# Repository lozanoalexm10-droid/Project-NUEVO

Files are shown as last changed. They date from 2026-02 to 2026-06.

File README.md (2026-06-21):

# MARSY

> **Mobile Autonomous Robotic SYstem**

| | | |
|---|---|---|
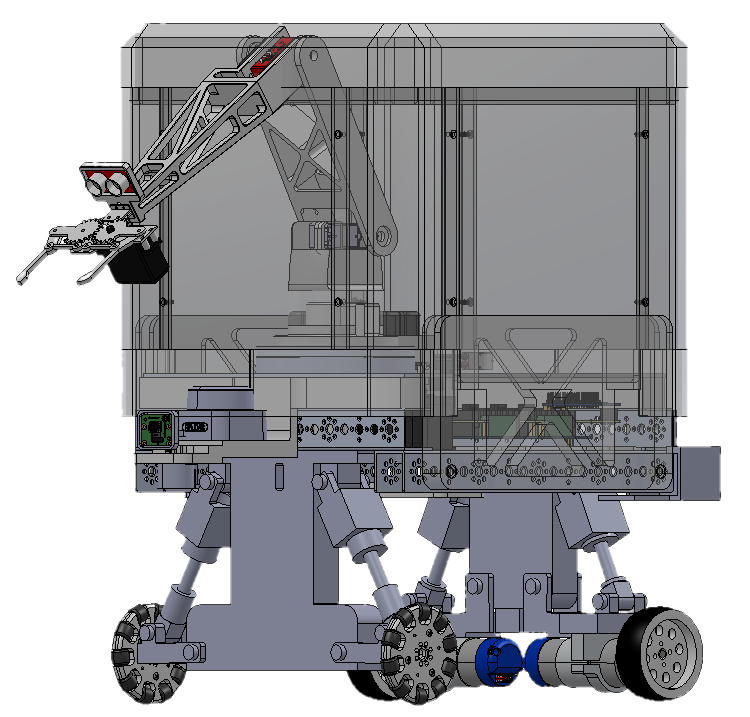
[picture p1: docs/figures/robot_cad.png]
Full assembly CAD
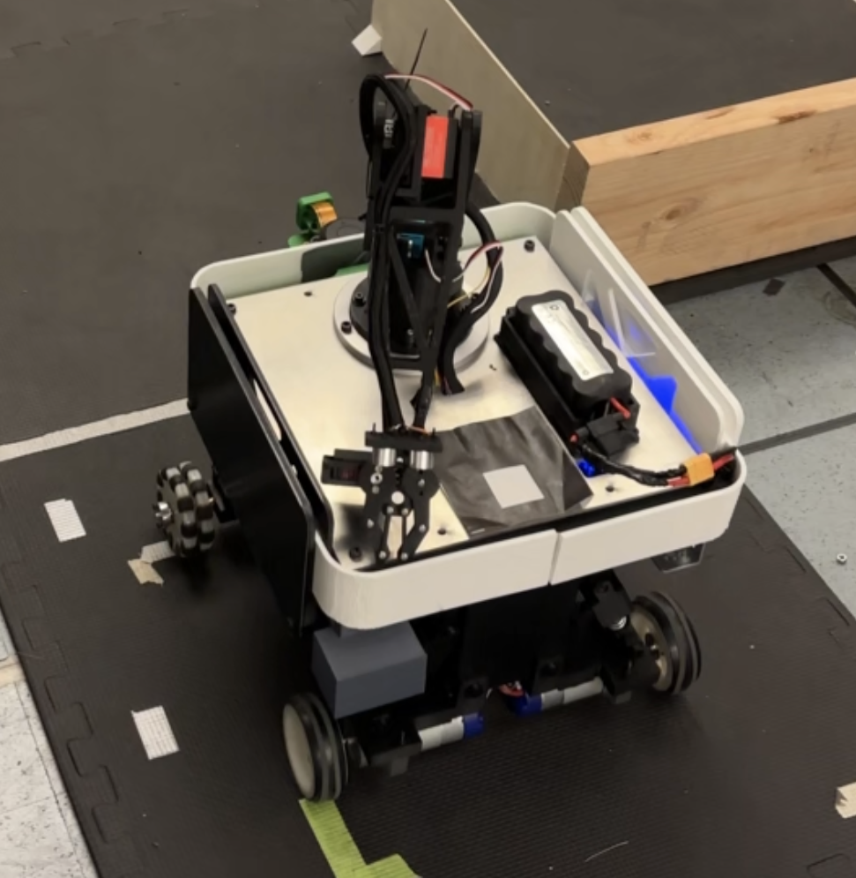
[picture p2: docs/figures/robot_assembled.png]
Operating configuration
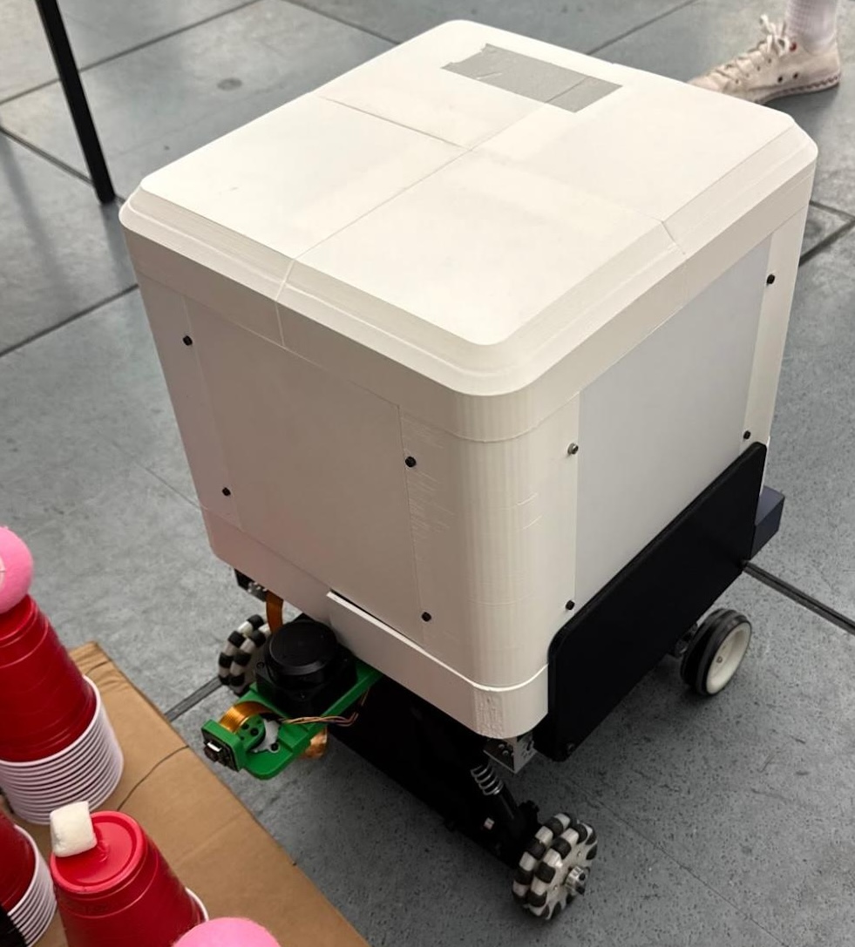
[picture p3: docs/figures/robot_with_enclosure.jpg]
Protective enclosure installed for drop and impact tests
|  |  |  |
| Full assembly CAD | Operating configuration (driving and manipulation) | Protective enclosure installed for the drop and impact tests |

MARSY is an autonomous differential-drive mobile manipulator built for the MAE 162D/E capstone, on top of the course's shared NUEVO electronics and firmware base. It drives a multi-segment competition course with LiDAR obstacle avoidance, then uses vision-guided inverse kinematics to identify the marshmallow-bearing cup stack, pick from it, and place the marshmallow on a plate.

---

## Project Overview

The team's contribution is the physical robot and the high-level autonomy program. The teaching team supplied a shared base that all capstone teams build on: a custom PCB, the Arduino firmware that drives it, the TLV link to the Pi, and a ROS 2 node skeleton.

From a kit of four aluminum U-channel pieces, two driven wheels, two omni wheels, and DC motors with mounts, we designed and built the chassis, the suspension, and a 3-DOF manipulator around a purchased metal gripper.

On top of the provided software we wrote the manipulator program for vision-guided cup-stack selection, closed-form inverse kinematics, and the pick-and-place FSM. We brought up and calibrated every sensor and actuator on the robot, added our own ROS 2 nodes where the skeleton didn't cover what we needed (e.g., the ultrasonic ranger), tuned the drive PID against encoder feedback, and reworked the provided pure-pursuit follower and obstacle-avoidance planner for the venue course.

See it run:

https://www.youtube.com/watch?v=NkwrqGURsrY

---

## Problem

Build a mobile manipulator that, with no operator intervention after a green-light go signal, can:

1. Navigate a multi-lane course at a competition venue, respecting lane geometry, an obstacle field, and a stop sign.
2. Park at a manipulation station and locate a single marshmallow that sits on one of four cup stacks of varying height.
3. Pick the marshmallow with a metal gripper, optionally roast it on a heating wire, and place it on a plate at a fixed offset.

Constraints:
- Hard real-time motor control on an Arduino Mega 2560, all higher logic on a Raspberry Pi 5.
- Communication between the two is a custom TLV protocol over a single UART link.
- A custom PCB integrates power delivery, motor drivers, and the Arduino footprint into a single board.
- No off-the-shelf navigation or manipulation stack. Perception, kinematics, and the demo FSM were written from scratch for this platform; pure-pursuit and the obstacle-avoidance planner were provided as starter code and reworked for the venue.

---

## Design and Approach

| Layer | Notes |
|---|---|
| **Mechanical** | Team-designed and team-built. Chassis, suspension, and a 3-DOF arm (turntable + shoulder + elbow) on a stepper-driven base, plus a camera-pan stepper, built from a starter kit (4 aluminum U-channels, 2 driven wheels, 2 omni wheels, DC motors + mounts), and a purchased metal gripper end effector. CAD in [`mechanical/`](mechanical/). A heating-wire roaster was designed and wired into the FSM but never installed mechanically (see Results). |
| **Custom PCB** | Provided by the teaching team. Arduino Mega 2560, dual DC motor drivers, stepper drivers, PCA9685 servo bus, LM61460 regulation. See [`nuevo_board/`](nuevo_board/). |
| **Arduino firmware** | Provided by the teaching team. Real-time motor PID, encoder odometry, stepper move queues, servo outputs, IMU + voltage monitoring, state-machine safety, and the TLV transport ([`firmware/`](firmware/), [`tlv_protocol/`](tlv_protocol/)). Drive PID gains were tuned by the team against the as-built drivetrain. |
| **Sensors** | Sensor selection was provided. The team mounted, wired, and calibrated the RPLIDAR C1, IMX477 camera, and Qwiic ultrasonic. The external GPS/ArUco localizer was built by the teaching team. The ICM-20948 IMU was dropped for the final demo due to magnetic interference from the electronics. |
| **ROS 2 stack** | Skeleton supplied (`bridge` TLV ⇆ ROS, `bridge_interfaces` msg/srv defs, `sensors`, `rplidar_ros`, `global_gps`, and the Robot API scaffolding inside `robot`). Team-added: ROS 2 nodes the skeleton didn't cover (e.g., the ultrasonic ranger), the `vision` package, and the high-level program inside the `robot` package consisting of FSMs, demo programs, manipulation code, and the perception/navigation integration that runs the demo ([`ros2_ws/src/`](ros2_ws/src/)). |
| **Perception** | Team-written. Detection for traffic lights, stop signs, marshmallows, and red cups, built on YOLO library pull-ins that the teaching team provided for the traffic-light and stop-sign detectors. |
| **Navigation** | Pure-pursuit follower and obstacle-avoidance scaffolding provided as starter code. Avoidance works by lane-switch waypoint regeneration: when a cone is detected, the planner inserts a hat-shaped detour (entry → hold past obstacle → return to center) into the remaining waypoint list. Team retuned both, added goal-y filtering so perimeter walls don't trigger detours, and wrote the four-segment venue FSM with a manual-reposition hold between segments. |
| **Manipulation** | Team-written. Closed-form 3-DOF inverse kinematics ([`arm_kinematics.py`](ros2_ws/src/robot/robot/arm_kinematics.py)) with explicit elbow-up branch selection; vision-driven stack selection; ultrasonic reach refinement; pick-and-place FSM. Documented in [`docs/manipulator.md`](docs/manipulator.md). |

### Software organization

The robot package follows a clean layout under `robot/programs/`:

```
robot/programs/
  demos/         the two headline programs
  navigation/    drive-only tests
  manipulation/  arm, servo, stepper, gripper, turntable, campan
  perception/    vision + lidar
  analysis/      data recording + plotting
  legacy/        archived earlier drafts
```

The two demo entry points are:
- [`full_competition_venue_run.py`](ros2_ws/src/robot/robot/programs/demos/full_competition_venue_run.py) for the full graded course
- [`precision_stack_manipulator_demo.py`](ros2_ws/src/robot/robot/programs/demos/precision_stack_manipulator_demo.py) for vision-driven pick-and-place

### Algorithms worth highlighting

- **Lane-switch waypoint-regeneration avoidance**: when a cone is detected, the planner inserts a hat-shaped detour into the remaining pure-pursuit path, with a goal-y filter that prevents the north wall from triggering detours.
- **Cup-pair vision detection** that confirms a marshmallow by matching its bearing against the nearest red-cup detection which is robust against tennis-ball decoys and false positives.
- **Closed-form IK with explicit branch selection**: the elbow can only fold one way, so we always select the "elbow up" branch deterministically.

---

## Results

The robot ran the venue course end-to-end and the manipulator ran the pick-and-place in isolation. The live demo had four visible issues that this section is honest about: the gripper would not release the marshmallow at the place pose, heading drift forced three manual repositions, the obstacle pass clipped one cone in the tight scenario, and odometry drift across a full venue run pushed the robot off the hardcoded cup positions, so the driving and the precision pick-and-place were demoed as separate programs. The platform itself (the team's mechanical build on top of the provided electronics and firmware) held up through the run.

### What worked

- **Full 4-segment venue navigation** including a U-turn, lane switch, and obstacle field
- **LiDAR lane-switch obstacle avoidance** (provided pure-pursuit avoidance planner, retuned for the venue) cleared 2 of 3 cones in the final run
- **Vision-guided stack selection** over the four hardcoded cup-stack positions: the vision selector reliably picks which stack contains the marshmallow when the robot starts from the known manipulation pose
- **Closed-form 3-DOF inverse kinematics** for both pick and place targets with deterministic elbow-up branch selection; the pick action ran end-to-end (place release did not; see below)
- **Localization**: the provided wheel-odometry + GPS/ArUco fusion kept the robot tracking the course (the ICM-20948 IMU was dropped for the final demo due to magnetic interference)
- **Stop-sign and traffic-light detection** in isolation during development
- **Protective enclosure passed both impact tests**: a basketball dropped onto the enclosure from 1 m and the robot itself dropped from 1 ft onto mats; the only damage was the press-fit top lid coming loose on impact, with no functional hardware harmed

### What didn't work in the live demo

- **Place-onto-plate release**: IK and FSM for the place pose were correct, and the gripper opened reliably at the pick pose, but would not open at the place pose. Most likely cause: the place reach extends the arm sideways with the gripper near-horizontal, gravity-loading the jaw closed against the MG996R's torque budget. A shoulder unload-lift (`UNLOAD_LIFT_DEG = 10°` in [`precision_stack_manipulator_demo.py`](ros2_ws/src/robot/robot/programs/demos/precision_stack_manipulator_demo.py)) wasn't enough to resolve it in the time we had.
- **Heading drift → three manual repositions**: the FSM intentionally pauses at segment boundaries (`MANUAL_REPOSITION_HOLD_S`) so the operator can re-place the robot at a known pose. We leaned on this hold rather than fighting drift autonomously.
- **Cone contact in the tight scenario**: the lane-switch avoidance cleared 2 of 3 cones but clipped one in the tight obstacle layout.
- **Stop-sign trigger didn't fire**: on the final run the robot drifted too far left of the lane center, and the stop sign sits on the far right of the lane, so the detector's range/bearing gate didn't trip. The detector usually works; we just didn't get enough end-to-end runs across the full demo to harden it, so the cause is essentially "robot was outside the gate region for this specific run." Code remains, gated by `STOP_SIGN_GATE_Y_MM` in [`full_competition_venue_run.py`](ros2_ws/src/robot/robot/programs/demos/full_competition_venue_run.py).
- **Integrated drive + pick (demos split)**: our first plan was to localize the marshmallow in free space with onboard sensors; that wasn't reliable, so we fell back to hardcoding the four candidate cup-stack positions and using vision only to pick among them. Even with the fallback, odometry drift after a full venue run left the robot off-pose relative to those hardcoded positions and the gripper would land in the wrong spot, so we ended up demoing the venue navigation and the precision pick-and-place as separate programs ([`full_competition_venue_run.py`](ros2_ws/src/robot/robot/programs/demos/full_competition_venue_run.py) and [`precision_stack_manipulator_demo.py`](ros2_ws/src/robot/robot/programs/demos/precision_stack_manipulator_demo.py)).

### What we cut

- **Heating-wire roast cycle**: software complete (the `PLACING → ROASTING` FSM transition and relay control path are wired in), but never installed in hardware. We couldn't find a safe way to mount an exposed heated element on a moving arm without unacceptable damage or burn risk, so the stage was cut by choice.

### Reference figures

| | |
|---|---|
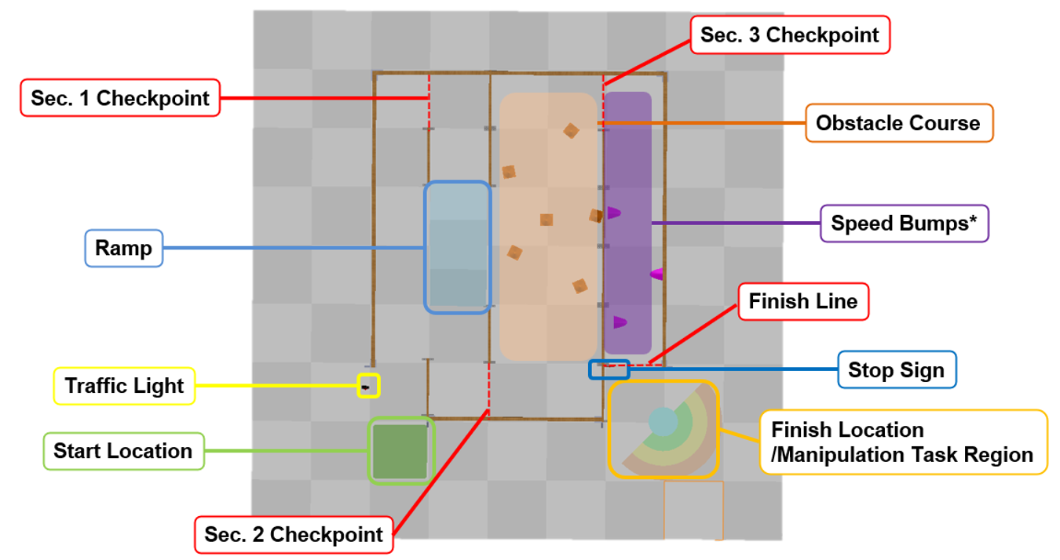
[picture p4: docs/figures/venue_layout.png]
Venue layout
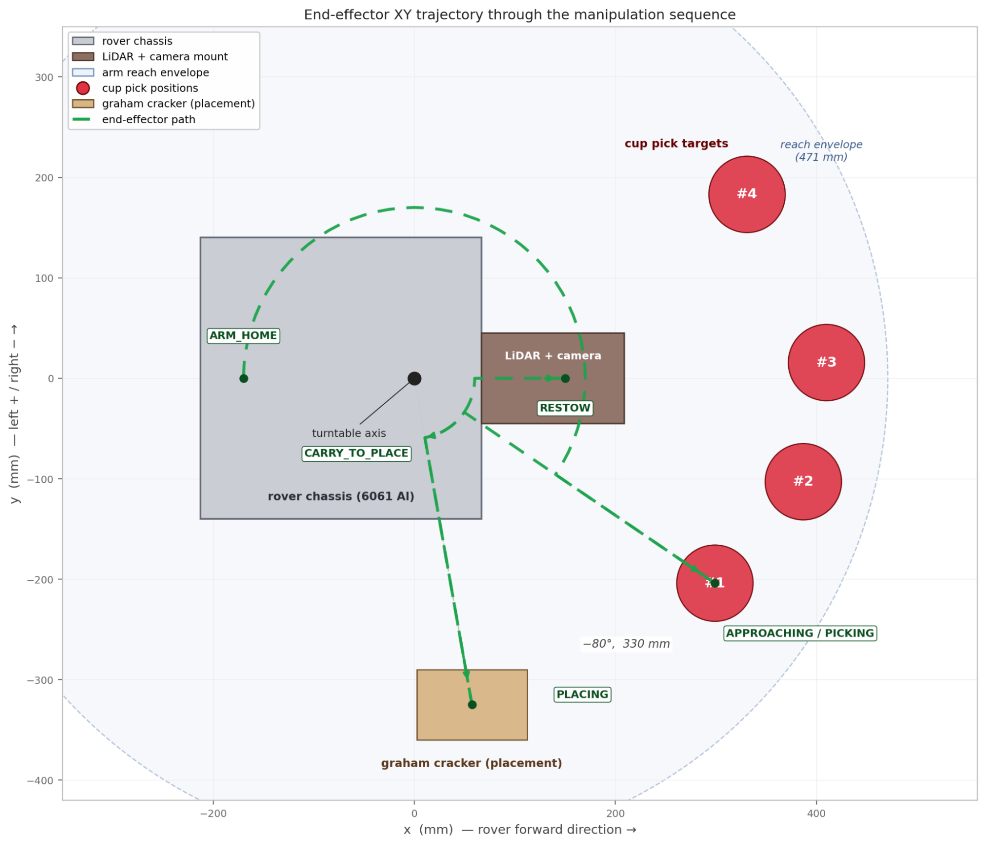
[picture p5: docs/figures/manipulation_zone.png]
Manipulation zone
|  |  |
| Annotated venue: start, segment checkpoints, ramp, obstacle course, traffic light, stop sign, finish line, and the manipulation task region. | Top-down view of the manipulation zone showing the rover footprint, LiDAR/camera mount, arm reach envelope, the four hardcoded cup-pick positions, the graham-cracker placement target, and a sample end-effector path. |
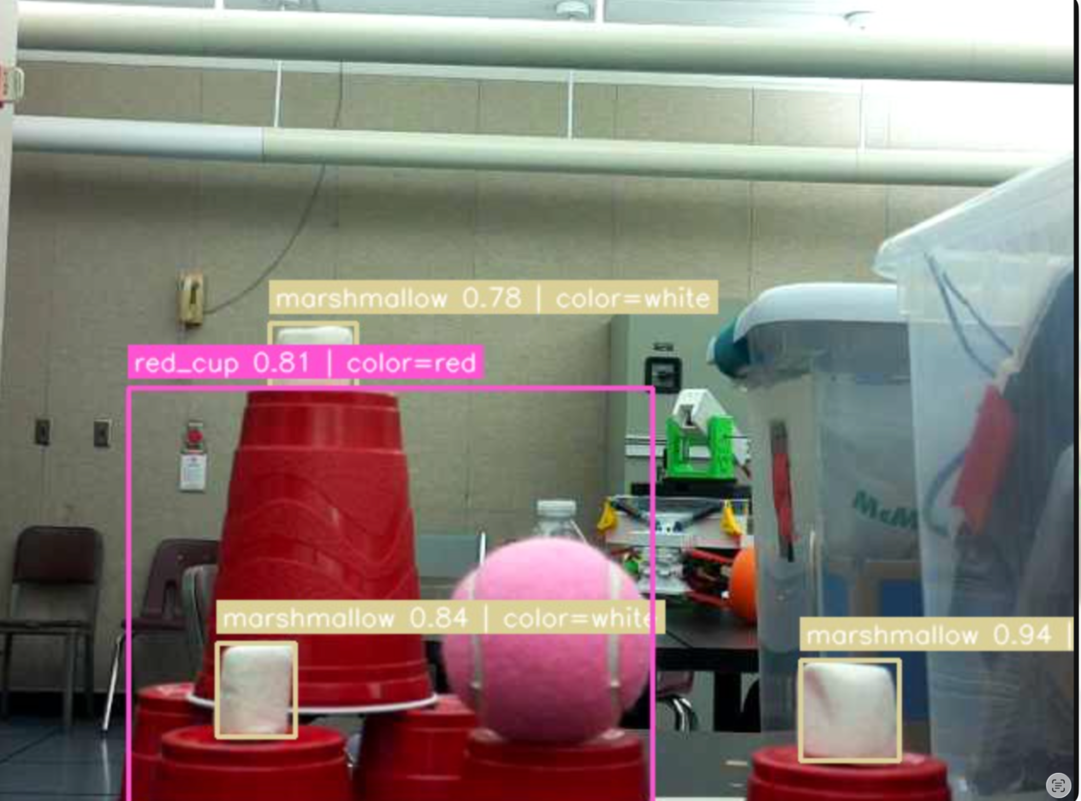
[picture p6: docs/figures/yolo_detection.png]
YOLO detection on a venue snapshot
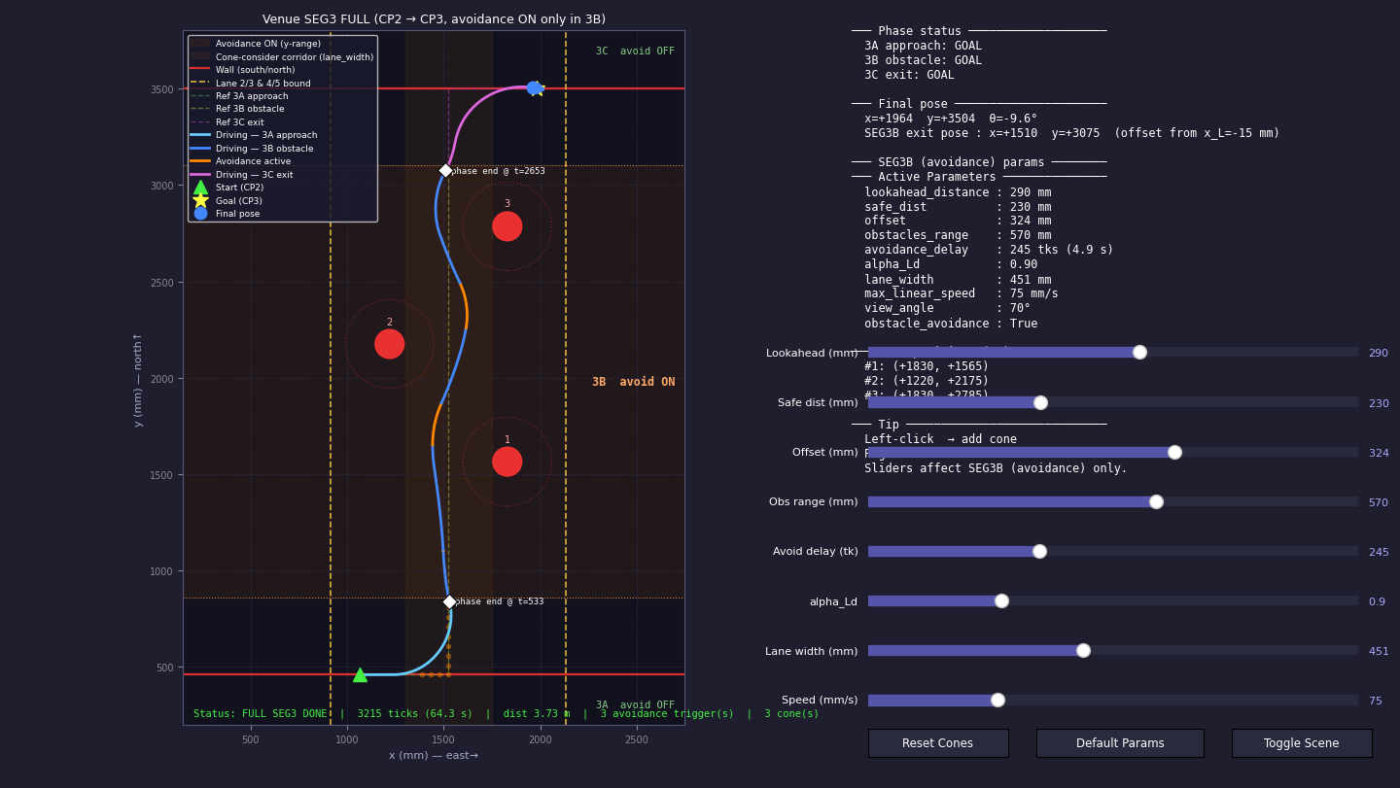
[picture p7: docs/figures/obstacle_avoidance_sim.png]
Obstacle-avoidance tuning sim
|  |  |
| Perception: YOLO detection with cup-pair color-coded confidences. The pink ball in frame is the tennis-ball decoy the cup-pair logic disambiguates against. | Obstacle-avoidance behavior simulator used to tune lane-switch parameters (lookahead, safe distance, lane offset, avoidance delay) against the cone field before each venue run. |

---

## How To Reproduce

### Hardware

Custom PCB and chassis as specified in [`nuevo_board/SPECIFICATIONS.md`](nuevo_board/SPECIFICATIONS.md) and [`mechanical/`](mechanical/). Build of materials and electrical references live in [`docs/`](docs/) (datasheets) and on the PCB schematic.

### One-time setup

Flash an Ubuntu 24.04 + ROS 2 Jazzy image to the Pi's SD card and put the Pi on the same WiFi as the workstation. Then:

```bash
git clone https://github.com/lozanoalexm10-droid/Project-NUEVO.git
cd Project-NUEVO

# Enable hardware UART, harden SysRq, install Docker + Compose, build the bridge frontend:
sudo bash ros2_ws/scripts/setup_rpi.sh

# Flash the Arduino firmware (see firmware/README.md)
```

### Run the full demo

Open four terminals on the Pi (the order matters: the robot node resets odometry on startup, so it must launch last):

| Terminal | Command |
|---|---|
| T1 | `docker compose -f ros2_ws/docker/docker-compose.rpi.yml up -d` |
| T2 | `ros2 launch robot everything_but_robot.launch.py` (LiDAR + GPS) |
| T3 | `ros2 launch vision vision_debug.launch.py` |
| T4 | `ros2 launch robot robot.launch.py` (always last) |

Select which program runs by uncommenting exactly one import in [`ros2_ws/src/robot/robot/main.py`](ros2_ws/src/robot/robot/main.py):

```python
from robot.programs.demos.full_competition_venue_run import run        # full course
#from robot.programs.demos.precision_stack_manipulator_demo import run # pick-and-place only
```

A `[FSM]` log on T4 traces every state transition during the run.

---

## Team Contributions

| Member | Contributions |
|---|---|
| **Todd Bell** | High-level autonomy software: manipulator program (inverse kinematics, vision-driven stack selection, pick-and-place FSM) and the venue-navigation FSM on top of the provided planners; belt-driven turntable subassembly design; simulation and parameter tuning for the obstacle-avoidance behavior and the manipulator workspace; sensor and actuator bring-up; electrical integration and motor/servo/stepper tuning; assembly, regular servicing, and demo testing |
| **Joanna Do** | Protective enclosure design and CAD; FEA impact analysis on the enclosure (drop-test load case); exploded-view documentation drawings; principal author of the team's final report; co-led project documentation throughout the build; assembly and regular servicing |
| **Lena Gudikunst** | Systems engineering and project administration; part procurement; suspension technical drawings and contributing CAD; co-led project documentation throughout the build; assembly and regular servicing |
| **Janice Hu** | Manipulator arm design and CAD; late-stage sensor mount design and integration; hardware verification to spec (reach, joint limits) and design iteration; primary lead on team mechanical assembly and regular servicing throughout the build |
| **Gerardo Lozano-Miranda** | Suspension CAD with multiple design iterations and stability analyses; sized the suspension across drop-survival cases that were stepped down over iterations from 1 m to 1 ft; differential-drive dynamics simulation; PID tuning via simulated open-loop → closed-loop transition; assembly and regular servicing |
| **William Tjandra** | Vision and detection work on the manipulator pipeline: HSV color filtering for marshmallow detection and a controlled matte-black workspace around the manipulation station to suppress false marshmallow detections from venue walls; soldering and electrical wiring; assembly and regular servicing |

---

## Links to More Detail

| Topic | Document |
|---|---|
| Cross-project docs index | [`docs/README.md`](docs/README.md) |
| Communication protocol | [`docs/COMMUNICATION_PROTOCOL.md`](docs/COMMUNICATION_PROTOCOL.md) |
| Design guidelines | [`docs/DESIGN_GUIDELINES.md`](docs/DESIGN_GUIDELINES.md) |
| Manipulator reference | [`docs/manipulator.md`](docs/manipulator.md) |
| Robot API reference | [`docs/robot_api_reference.md`](docs/robot_api_reference.md) |
| Firmware overview | [`firmware/README.md`](firmware/README.md) |
| PCB specifications | [`nuevo_board/SPECIFICATIONS.md`](nuevo_board/SPECIFICATIONS.md) |
| TLV payload layouts | [`tlv_protocol/TLV_Payloads.md`](tlv_protocol/TLV_Payloads.md) |
| Robot package README | [`ros2_ws/src/robot/README.md`](ros2_ws/src/robot/README.md) |
| Programs README | [`ros2_ws/src/robot/robot/programs/README.md`](ros2_ws/src/robot/robot/programs/README.md) |
| ROS 2 setup notes | [`docs/ros2/`](docs/ros2/) |

---

## Repository Map

```
firmware/        Arduino Mega 2560 firmware
nuevo_ui/        Raspberry Pi bridge + web UI
ros2_ws/         ROS 2 workspace
  src/
    bridge/              ROS ⇆ TLV firmware bridge
    bridge_interfaces/   custom msg/srv definitions
    sensors/             Pi-side sensor ROS nodes
    vision/              camera + perception nodes
    rplidar_ros/         RPLIDAR C1 driver
    global_gps/          GPS + ArUco ground-truth localizer
    robot/               high-level FSM, Robot API, planners, programs
tlv_protocol/    typed TLV definitions + code generators
nuevo_board/     PCB schematic, layout, BOM, datasheets
mechanical/      CAD for chassis and manipulator
docs/            cross-project documentation
assets/          branding
```

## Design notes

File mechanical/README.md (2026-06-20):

# Mechanical Design

CAD files for the team-designed mechanical platform — chassis, suspension, manipulator, and protective enclosure.

## Contents

- [`stl/`](stl/) — STL exports of every team-designed part, organized by subassembly:
  - [`Chassis/`](stl/Chassis/) — chassis frame, motor mounts, electronics tray
  - [`Suspension/`](stl/Suspension/) — front and rear double-wishbone components
  - [`Manipulator/`](stl/Manipulator/) — arm linkages, gripper mount, turntable
  - [`Enclosure/`](stl/Enclosure/) — drop-test enclosure shell and panels

  GitHub renders STLs inline as interactive 3D models — click any file to rotate it in the browser.

- [`drawings/`](drawings/) — Formal 2D mechanical drawings (PDF), organized by subassembly:
  - [`0.0 Top Assembly/`](drawings/0.0%20Top%20Assembly/)
  - [`3.0 Manipulator-Mobile Interface/`](drawings/3.0%20Manipulator-Mobile%20Interface/)
  - [`3.1 Mobile Robot/`](drawings/3.1%20Mobile%20Robot/)
  - [`3.2 Manipulator Robot/`](drawings/3.2%20Manipulator%20Robot/)

- [`NUEVO baord/`](NUEVO%20baord/) — STEP file for the provided NUEVO PCB assembly, used as a fit/clearance reference during chassis design.

The full SolidWorks part files, library parts, purchased models, and live top assembly live in the team's Box folder and aren't tracked here to keep the repo lean.

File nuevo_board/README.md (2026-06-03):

# The NUEVO Board - User Guide
**Navigation Unit for Education and Versatile Operations**

**Board Revision:** Rev. B
**Design Status:** Designed and fabricated (awaiting delivery and testing)
**Last Updated:** 2026-02-13
 
---
 
## Overview

The NUEVO Board is the main controller board for the MAE 162 educational robotics platform. It integrates power management, motor control interfaces, and communication between the Arduino Mega 2560 microcontroller and Raspberry Pi 5.

**Design Philosophy:** This board uses a modular architecture with off-the-shelf motor driver and PWM modules. The custom PCB focuses on robust power management, clean signal interfaces, and educational accessibility.

**Key Features:**
- Dual DC-DC buck converters (5V for logic, adjustable 5-10V for servos)
- Support for 4 DC motors with quadrature encoders (full 4x resolution)
- Support for 4 stepper motors (A4988/DRV8825 driver sockets)
- Support for up to 16 servos (via external PCA9685 module)
- Arduino ↔ Raspberry Pi UART communication with level shifting
- 6 Qwiic connectors for I2C sensor expansion (4 Arduino, 2 RPi)
- 10 user buttons / limit switches
- RGB LED strip support (WS2812B)

---

## Quick Specifications

### Power System
- **Input:** 12V NiMH battery (default), supports 7.4V-24V (via XT60 connector)
- **5V Rail:** Up to 6A (Raspberry Pi 5, Arduino, sensors, encoders)
- **Servo Rail:** Adjustable 5-10V @ 6A (potentiometer adjustable, default ~6V)
- **Protection:** 15A replaceable fuse, reverse polarity protection, power switch

### Motor Control (External Modules)
- **DC Motors:** 4 motors via 2 dual-channel H-bridge modules (external)
  - Encoder support: 4x quadrature resolution on all motors
  - Current sensing on all channels
- **Stepper Motors:** 4 sockets for A4988/DRV8825 driver modules (on-board)
- **Servo Motors:** Up to 16 servos via PCA9685 I2C PWM module (external)

### Communication
- **Arduino ↔ Raspberry Pi:** UART Serial2 (pins 16/17) with 5V ↔ 3.3V level shifting
- **I2C Expansion:** 6 Qwiic connectors (JST-SH 4-pin)
  - 4 on Arduino bus (voltage-selectable: 5V or 3.3V per bank)
  - 2 on Raspberry Pi bus (3.3V only)

### User Interface
- **LEDs:** 5 status/user LEDs (red, green, blue, orange, purple)
- **RGB LED:** 1 on-board WS2812B + extension socket for external strips
- **Buttons:** 2 dedicated on-board buttons + 8 dual-purpose button/limit switch inputs
- **Power Indicators:** 5V rail LED, servo rail LED, power-good LED

---

## Getting Started

### 1. Initial Inspection

**Before powering up:**
- [ ] Visually inspect PCB for damage, solder bridges, or loose components
- [ ] Verify all module connections are secure (H-bridge, stepper drivers, PCA9685)
- [ ] Check fuse is properly seated (15A blade fuse)
- [ ] Ensure power switch is in OFF position

### 2. Power Requirements

**Battery:**
- **Recommended:** 12V NiMH battery pack (10-14.4V range)
- **Supported:** 7.4V-24V (2S to 6S LiPo, or equivalent)
- **Connector:** XT60 male on battery cable (female on PCB)
- **Capacity:** Minimum 2000mAh recommended for typical operation

**⚠️ IMPORTANT - H-Bridge Voltage Limit:**
- Default H-bridge modules (DC5-12V 30A Dual Channel) support **5-12V maximum**
- If using batteries >12V (e.g., 4S-6S LiPo), replace with higher-voltage modules (e.g., BTS7960 for 24V)
- Always match H-bridge voltage rating to your battery voltage

### 3. First Power-Up Checklist

**Step-by-step:**
1. **Install fuse:** Insert 15A blade fuse into holder
2. **Connect battery:** Plug in XT60 connector (observe polarity - reverse polarity protection is active)
3. **Set servo voltage:** Adjust potentiometer if needed (default ~6V is safe for most servos)
4. **Power ON:** Flip main power switch
5. **Check LEDs:**
   - 5V power indicator (green) should illuminate
   - Servo rail power indicator (green) should illuminate
   - Power-good LED should illuminate (indicates 5V buck is active)
6. **Verify voltages:**
   - Measure 5V rail with multimeter: Should read 4.9-5.1V
   - Measure servo rail: Should match potentiometer setting (5-10V)
7. **Upload firmware:** Connect Arduino via USB and upload test firmware
8. **Check ROS2 communication:** Power Raspberry Pi 5 and test UART bridge

---

## Board Layout & Connectors

### Power Connectors

| Connector | Type | Location | Function |
|---|---|---|---|
| **J_BAT** | XT60 female | Left edge | Battery input (7.4V-24V) |
| **SW1** | Toggle/rocker switch | Left edge | Main power ON/OFF |
| **F1** | Blade fuse holder | Near battery input | 15A replaceable fuse |
| **POT_SERVO** | Trimmer potentiometer | Center area | Servo rail voltage adjustment (5-10V) |

### Motor Connectors

**DC Motors (H-Bridge Module Interface):**
- **J_M1_CTRL**, **J_M2_CTRL**: Motor 1/2 control headers (EN, IN1, IN2, CT pins)
- **J_M3_CTRL**, **J_M4_CTRL**: Motor 3/4 control headers (EN, IN1, IN2, CT pins)
- **J_M1_ENC** to **J_M4_ENC**: 4-pin encoder headers (VCC, GND, A, B)

**Stepper Motors (On-Board Driver Sockets):**
- **U_ST1** to **U_ST4**: A4988/DRV8825 driver module sockets
- **JP_MS1_1** to **JP_MS3_4**: Microstepping jumpers (3 per driver × 4 drivers = 12 jumpers)
- **J_ST1_MOTOR** to **J_ST4_MOTOR**: 4-pin motor connectors (A+, A-, B+, B-)

**Servo Motors (PCA9685 Interface):**
- **J_PCA9685**: 4-pin header (VCC, GND, SDA, SCL) connects to external PCA9685 module
- Servos plug into PCA9685 module, not directly into main PCB

### Communication Connectors

**Qwiic I2C (Arduino Bus - 3.3V, Level-Shifted):**
- **J_QWIIC_1** to **J_QWIIC_4**: 4 Qwiic connectors (JST-SH 4-pin, 1mm pitch)
- All connectors on Arduino I2C bus (pins 20/21 SDA/SCL)
- **Voltage:** 3.3V (compatible with all Qwiic/STEMMA QT devices)
- **Level shifting:** TXS0102 translates Arduino 5V ↔ Qwiic 3.3V automatically
- **Pin definition** (for custom cables):
  - Pin 1: GND (black wire)
  - Pin 2: 3.3V (red wire)
  - Pin 3: SDA (blue wire)
  - Pin 4: SCL (yellow wire)

**Qwiic I2C (Raspberry Pi Bus - 3.3V Native):**
- **J_QWIIC_RPI1**, **J_QWIIC_RPI2**: 2 connectors on RPi I2C bus (GPIO2/GPIO3)
- **Voltage:** 3.3V (no level shifting needed)
- Same pin definition as Arduino Qwiic connectors

**Arduino ↔ Raspberry Pi UART:**
- Internal connection via level shifter (not externally exposed)
- Arduino Serial2 (pins 16/17) ↔ RPi GPIO14/GPIO15

### User Interface Connectors

**Buttons (On-Board):**
- **BTN1**, **BTN2**: Dedicated user buttons (pins 38, 39)

**Dual-Purpose Button/Limit Switch Inputs:**
- **BTN3/LIM1** to **BTN10/LIM8**: 8 dual-purpose inputs (pins 40, 41, 48-53)
- Each has on-board tactile button + 3-pin JST XH connector (V, S, G)
- **JP_LIM_V**: 3-pin jumper selects VCC for all limit switch connectors (5V or 3.3V)

**LEDs:**
- **LED1** (Green): System OK indicator (pin 44, PWM)
- **LED2** (Red): Error/low battery indicator (pin 5, digital only - no PWM)
- **LED3** (Blue): User LED (pin 45, PWM, exposed)
- **LED4** (Orange): User LED (pin 46, PWM, exposed)
- **LED5** (Purple): User LED (pin 47, digital only, exposed)

**RGB LED:**
- **D_RGB1**: On-board WS2812B LED (pin 42)
- **J_NEOPIXEL**: 3-pin extension socket (DIN, 5V, GND) for external LED strips

---

## Configuration & Jumpers

### 1. Servo Power Jumper (PCA9685)

**JP_SERVO_PWR (PCA9685 Power Enable):**
- **Jumper CLOSED (installed):** Servo rail power connected directly to PCA9685 VCC
  - **Benefit:** No external power cable needed for PCA9685 module
  - **Use case:** Standard setup when using on-board servo power
- **Jumper OPEN (removed):** PCA9685 powered externally
  - **Use case:** When using separate servo power supply or troubleshooting

**Default:** Jumper CLOSED (most common configuration)

**⚠️ Note:** The servo rail voltage is adjustable (5-10V via POT_SERVO). Ensure PCA9685 and connected servos can handle the selected voltage before enabling this jumper.

### 2. Limit Switch Voltage Selection

**JP_LIM_V (All 8 limit switch connectors share this setting):**
- **Position 1-2 (5V):** Use for 5V sensors (mechanical switches, 5V optical endstops)
- **Position 2-3 (3.3V):** Use for 3.3V sensors (some Hall effect, low-voltage proximity sensors)

**Default:** 5V (suitable for mechanical switches and most common optical endstops)

### 3. Stepper Microstepping Configuration

**Each stepper driver has 3 jumpers (MS1, MS2, MS3):**

**Microstepping Table (A4988 and DRV8825):**

| JP_MS1 | JP_MS2 | JP_MS3 | A4988 Mode | DRV8825 Mode |
|---|---|---|---|---|
| Open | Open | Open | Full step  | Full step |
| Closed | Open | Open | 1/2 step | 1/2 step |
| Open | Closed | Open | 1/4 step | 1/4 step |
| Closed | Closed | Open | 1/8 step | 1/8 step |
| Closed | Closed | Closed | 1/16 step  | 1/32 step |

**Recommended Settings:**
- **1/16 microstepping (A4988):** Smooth motion, good for most applications
- **1/8 microstepping:** Balance between smoothness and speed
- **Full step:** Maximum speed, used for rapid positioning

**Configuration:**
- Jumper CLOSED = Insert jumper cap (shorted)
- Jumper OPEN = Remove jumper cap

### 4. Servo Rail Voltage Adjustment

**POT_SERVO (Trimmer potentiometer):**
- **Range:** 5V to 10V (adjustable)
- **Default:** ~6V (set at factory, safe for standard servos)
- **Adjustment:** Turn clockwise to increase voltage, counterclockwise to decrease

**How to Set:**
1. Power on the board
2. Measure voltage at servo rail test point (or PCA9685 VCC) with multimeter
3. Adjust potentiometer slowly until desired voltage is reached
4. Common settings:
   - **5-6V:** Standard analog servos
   - **6-7.4V:** High-torque servos
   - **7.4-8.4V:** Digital servos (check servo specs)

**⚠️ WARNING:** Do not exceed servo voltage rating! Most standard servos are rated for 4.8V-6V.

---

## Usage Guidelines

### Power Budget and Current Limits

**15A Fuse (Default):**
- Adequate for typical operation (2-3 motors running, servos idle)
- **Peak currents** (all motors stalled) can exceed 15A and blow fuse
- Replace fuse with 20A if running heavy-duty applications

**Staggered Motor Startup:**
- Avoid starting all motors simultaneously (reduces inrush current)
- Firmware should implement sequential startup where possible

### H-Bridge Voltage Compatibility

**Default H-Bridge Module (DC5-12V 30A Dual Channel):**
- **Maximum:** 12V (do NOT use with batteries >12V)
- **Minimum:** 5V (battery voltage directly powers motors)

**If using >12V batteries:**
- Replace with BTS7960 H-bridge modules (5-27V rating)
- Or use voltage regulator to step down battery voltage to motor supply

### Arduino Pin Usage Notes

**Serial Ports:**
- **Serial0 (USB):** Programming and debug only
- **Serial2 (pins 16/17):** Reserved for Raspberry Pi communication (do NOT use for other purposes)
- **Serial1 (pins 18/19):** NOT AVAILABLE (used for M2 encoder interrupts)
- **Serial3 (pins 14/15):** NOT AVAILABLE (used for stepper STEP signals)

**PWM Limitations:**
- **Pin 5 (LED_RED):** Digital ON/OFF only (no PWM or breathing - Timer 3 conflict with steppers)
- **Pin 47 (LED_PURPLE):** Digital ON/OFF only (not PWM-capable)

**Interrupt Pins (Rev. B):**
- **INT0 (pin 2):** M1_ENC_A (highest priority)
- **INT1 (pin 3):** M1_ENC_B
- **INT4 (pin 19):** M2_ENC_B
- **INT5 (pin 18):** M2_ENC_A
- **PCINT (pins 11, 12):** M4_ENC_A, M4_ENC_B
- **PCINT (A14, A15):** M3_ENC_A, M3_ENC_B

### Encoder Configuration (Firmware)

**4x Quadrature Mode (All Motors):**
- Motors 1 and 2 (wheels): Full hardware interrupts (INT0-INT5)
- Motors 3 and 4 (manipulators): Pin Change Interrupts (PCINT)
- All motors support full 4x resolution (1440 PPR → 5760 counts/rev)

**Encoder Power:**
- All encoders powered from 5V rail (~20mA each)
- Encoder VCC pins have 100nF decoupling capacitors

---

## Troubleshooting

### Power Issues

**No LEDs illuminate when power switch is ON:**
- Check fuse is properly seated and not blown (visual inspection)
- Verify battery voltage at XT60 connector with multimeter (should be 7.4V-24V)
- Check power switch is in correct position
- Measure voltage after fuse (should match battery voltage)

**5V power indicator OFF, but battery voltage present:**
- 5V buck converter may have shut down due to overcurrent or thermal protection
- Disconnect all loads (unplug Raspberry Pi, modules)
- Power cycle and check if 5V LED illuminates
- If still off, buck converter may be damaged

**Servo rail indicator OFF:**
- Check servo rail buck converter enable pin (should be pulled high)
- Measure input voltage to buck converter (should match battery)
- Adjust potentiometer and verify output changes (5-10V range)

**Power-good LED behavior:**
- **ON:** 5V power from buck converter (normal)
- **OFF:** 5V backfed from Raspberry Pi USB-C (ideal diode blocking buck)
- **Flickering:** Potential voltage conflict or unstable 5V rail

### Motor Control Issues

**DC motors not responding:**
- Check H-bridge module power connections (V+, GND from battery rail)
- Verify Arduino PWM and direction pins are connected to correct H-bridge inputs
- Measure voltage at H-bridge EN pin (should be PWM signal, 0-5V)
- Test motor directly with bench power supply to rule out motor failure

**Encoders not counting:**
- Check encoder power (5V, GND) at encoder connector
- Verify encoder signal wires (A, B) are connected to correct Arduino pins
- Use oscilloscope to verify encoder generates pulses when motor shaft rotates
- Check firmware ISR handlers are enabled for correct pins

**Steppers not moving:**
- Verify stepper driver module is properly seated in socket
- Check stepper motor coil connections (A+, A-, B+, B-) are correct
- Measure voltage at driver STEP pin (should see pulses when moving)
- Check driver ENABLE pin is LOW (active low enable)
- Verify motor power (VMOT) is present on driver module

### Communication Issues

**Arduino-Raspberry Pi UART not working:**
- Check level shifter power (5V on Arduino side, 3.3V on RPi side)
- Verify UART pins: Arduino TX2 (16) → RPi RXD (GPIO15), Arduino RX2 (17) ← RPi TXD (GPIO14)
- Test with loopback: Short TX to RX on one side and send test data
- Check baud rate matches on both sides (115200 or 230400)

**I2C devices not detected:**
- Verify correct Qwiic voltage jumper setting (5V or 3.3V) for your device
- Check I2C pull-up resistors are present (should measure ~2.5V on idle bus)
- Use I2C scanner sketch to detect device addresses
- Verify SDA/SCL are not swapped

**Qwiic connectors not working:**
- Check which bank (A or B) and which bus (Arduino or RPi)
- Arduino banks A and B are on same I2C bus (pins 20/21) - voltage jumpers only affect level shifting
- RPi Qwiic connectors are separate bus (GPIO2/3) - always 3.3V

### LED/Button Issues

**Status LEDs not working:**
- Check Arduino pin assignments in firmware match PCB (see pin table)
- For LED_RED (pin 5): Digital ON/OFF only, PWM disabled due to Timer 3 conflict
- Measure voltage at LED pin (should be 0V when OFF, 5V when ON)

**User buttons not responding:**
- Verify INPUT_PULLUP mode is enabled in firmware
- Check button pins read HIGH when not pressed, LOW when pressed
- Test with multimeter: Measure pin voltage (should be ~5V idle, ~0V pressed)

**Limit switches triggering incorrectly:**
- Check limit switch voltage jumper (JP_LIM_V) matches sensor requirements
- Verify limit switch type (normally-open vs normally-closed)
- Adjust firmware pin mode (INPUT_PULLUP for most sensors)

### Thermal Issues

**Buck converters overheating:**
- Normal: Converters may reach 60-80°C under load (warm to touch)
- Excessive: >100°C indicates problem (too hot to touch)
- Reduce load current or add heatsinks to converter ICs
- Verify thermal vias are connected to bottom ground plane

---

## Safety Warnings

⚠️ **IMPORTANT SAFETY INFORMATION:**

1. **Never hot-plug motors or high-current connections** while board is powered
2. **Always verify voltage settings** before connecting new modules
3. **Do not exceed 15A continuous draw** without upgrading fuse and verifying trace capacity
4. **Ensure proper ventilation** for DC-DC converters under heavy load
5. **Use appropriate wire gauge** for motor power (≥18 AWG for high-current motors)
6. **Keep exposed conductors away from metal chassis** to prevent shorts

---

## About the Name

**NUEVO** = **N**avigation **U**nit for **E**ducation and **V**ersatile **O**perations

The NUEVO Board is designed as a flexible, modular platform for teaching robotics concepts while supporting diverse project configurations - from wheeled robots to manipulator arms.

---

## Additional Resources

- **Technical Specifications:** See `SPECIFICATIONS.md` for complete electrical and mechanical details
- **Pin Assignments:** Detailed pin tables in `SPECIFICATIONS.md` (Rev. A and Rev. B)
- **Firmware Guide:** See `../firmware/README.md` for Arduino code examples and configuration
- **ROS2 Integration:** See `../ros2_ws/README.md` for Raspberry Pi setup and UART protocol
- **Schematic & Layout:** See `schematic/` and `layout/` folders for PDF exports

---

## Revision History

| Version | Date | Changes |
|---|---|---|
| **Rev. B** | 2026-02 | Full 4x encoder support on all motors, relocated pins for interrupt optimization, Timer 3 conflict resolved |
| **Rev. A** | 2025-12 | Initial production design |

---

**For technical support or questions, contact the MAE 162 instructional team.**

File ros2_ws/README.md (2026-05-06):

# ROS2 Workspace

This folder contains the ROS2 side of Project NUEVO.

The current ROS2 design keeps the workspace small and beginner-friendly:

- `bridge_interfaces` defines the raw firmware and bridge-facing ROS interfaces
- `bridge` wraps the shared `nuevo_bridge` runtime and exposes ROS topics and services
- `robot` is the main robot application package
- `sensors` is for Raspberry Pi connected sensors outside the Arduino firmware
- `vision` is for camera and perception code

If you are new to ROS2, read these files in order:

1. [docs/ros2/ros2_nodes_design.md](../docs/ros2/ros2_nodes_design.md)
2. [docs/ros2/bridge_runtime.md](../docs/ros2/bridge_runtime.md)
3. this README

## Package Layout

```text
ros2_ws/
├── src/
│   ├── bridge_interfaces/   # raw bridge-facing ROS interfaces that mirror the current protocol
│   ├── bridge/              # ROS wrapper around the shared nuevo_bridge runtime
│   ├── robot/               # main robot logic, bringup, config, URDF, RViz
│   ├── sensors/             # Pi-side sensor nodes outside the Arduino firmware
│   └── vision/              # camera and perception nodes
├── docker/                  # Docker image, compose files, and entrypoint scripts
└── README.md
```

Workspace-level ROS2 docs now live in:

```text
docs/ros2/
```

## Shared Runtime Model

The ROS bridge does not duplicate the web bridge.

- The shared Python runtime lives in [nuevo_ui/backend/nuevo_bridge](../nuevo_ui/backend/nuevo_bridge)
- The ROS package lives in [src/bridge](src/bridge)
- In ROS mode, one integrated `bridge` process owns:
  - one serial connection to the Arduino
  - one decode path
  - one FastAPI/WebSocket UI server
  - one ROS node

That means the UI and ROS always see the same decoded firmware state and use the
same outbound command path.

## Raw ROS API

The raw ROS topics use the same lowercase snake_case names as the bridge and
firmware protocol. Examples:

- `/sys_state`
- `/sys_power`
- `/dc_state_all`
- `/step_state_all`
- `/sensor_imu`
- `/sensor_kinematics`
- `/dc_set_velocity`
- `/dc_home`
- `/sensor_mag_cal_cmd`

This workspace intentionally treats those raw topics as the primary internal ROS
API. Standard ROS topics such as `/odom` or `/imu/data` can be added later as
adapters if needed.

See [docs/COMMUNICATION_PROTOCOL.md](../docs/COMMUNICATION_PROTOCOL.md) for the
protocol naming and semantics that these topics mirror.

## Command API Rule

Use the ROS API based on how the command behaves:

- use services for discrete actions where the caller expects success, rejection, or timeout
- use topics for continuous setpoints or frequently updated control inputs

Current example:

- `/set_firmware_state` uses `bridge_interfaces/srv/SetFirmwareState`
- `/dc_set_velocity` uses `bridge_interfaces/msg/DCSetVelocity`
- `/dc_set_pwm` uses `bridge_interfaces/msg/DCSetPwm`

The raw `/sys_cmd` topic still exists for low-level debugging, but normal ROS
callers should prefer `/set_firmware_state`.

## Workflow Overview

Docker is the default workflow for ROS2 because ROS2 Jazzy officially targets
Ubuntu 24.04, while the project may be developed on Raspberry Pi OS / Ubuntu,
macOS, or Windows.

Two compose files are provided:

| Platform | Compose file | Mode |
|---|---|---|
| Raspberry Pi with Arduino | `ros2_ws/docker/docker-compose.rpi.yml` | real hardware |
| macOS / Windows | `ros2_ws/docker/docker-compose.vm.yml` | mock bridge |

Important:

- `docker compose build` rebuilds the Docker image layers
- the container entrypoint runs `colcon build` each time the container starts
- `/ros2_ws/build` and `/ros2_ws/install` are cached in named Docker volumes
- `docker compose up` prepares the workspace but does not automatically start ROS nodes

## First-Time Setup

### 1. Choose the Compose File

From the repository root:

#### Raspberry Pi

```bash
COMPOSE=ros2_ws/docker/docker-compose.rpi.yml
```

#### macOS / Windows

```bash
COMPOSE=ros2_ws/docker/docker-compose.vm.yml
```

### 2. Raspberry Pi UART Setup

If you are using a real Raspberry Pi 5 with the Arduino bridge, enable UART
first. A shorter reference is also in
[`docs/ros2/rpi_setup.md`](../docs/ros2/rpi_setup.md).

```bash
sudo nano /boot/firmware/config.txt
```

Make sure it contains:

```text
enable_uart=1
dtoverlay=uart0-pi5
```

Then remove any serial-console entry from:

```bash
sudo nano /boot/firmware/cmdline.txt
```

Examples to remove:

```text
console=serial0,115200
console=ttyAMA0,115200
```

Reboot and verify:

```bash
ls -l /dev/ttyAMA0
```

The current bridge runtime expects:

```text
/dev/ttyAMA0 @ 200000 baud
```

### 3. Raspberry Pi Camera Setup

If the Pi CSI camera is used, install the native Ubuntu camera service before
starting the ROS2 container:

```bash
./ros2_ws/host_camera/install.sh
```

The installer creates a host-managed v4l2loopback camera at:

```text
/dev/video10
```

The ROS2 container mounts that virtual camera as a regular V4L2 device. Students
should not need to install or debug `libcamera` inside Docker.

### 4. Build the Frontend Once

On the Raspberry Pi, `sudo ./ros2_ws/setup_rpi.sh` now builds the frontend and
copies it into `nuevo_ui/backend/static/` automatically.

If you need to rebuild the UI manually after frontend changes, run:

```bash
cd nuevo_ui/frontend
npm ci
npm run build
cd ../..
cp -r nuevo_ui/frontend/dist/. nuevo_ui/backend/static/
```

### 5. Start the Container

From the repository root:

```bash
docker compose -f $COMPOSE build
docker compose -f $COMPOSE up -d
docker compose -f $COMPOSE logs -f ros2_runtime
```

Wait until the log shows that `colcon build` finished and the container is
ready.

### 6. Camera Sanity Check

If the Pi CSI camera is used, run this from the Raspberry Pi host after the ROS2
container is running:

```bash
./ros2_ws/host_camera/check.sh
```

The check captures one frame on the host and one frame from inside the Docker
container:

```text
/tmp/nuevo_camera_check/host_loopback.jpg
/tmp/nuevo_camera_check/docker_loopback.jpg
```

### 7. Enter the Running Container

Use the helper script:

```bash
./ros2_ws/docker/enter_ros2.sh        # default: rpi
./ros2_ws/docker/enter_ros2.sh rpi    # real hardware compose file
./ros2_ws/docker/enter_ros2.sh vm     # mock compose file
COMPOSE=ros2_ws/docker/docker-compose.rpi.yml ./ros2_ws/docker/enter_ros2.sh
./ros2_ws/docker/enter_ros2.sh --help
```

The helper:

- selects the compose file
- runs `docker compose exec`
- sources `/opt/ros/jazzy/setup.bash`
- sources `/ros2_ws/install/setup.bash`
- drops you into `/ros2_ws`

Manual fallback:

```bash
docker compose -f $COMPOSE exec ros2_runtime bash
source /opt/ros/jazzy/setup.bash
source /ros2_ws/install/setup.bash
cd /ros2_ws
```

### 8. Sanity Check the Workspace

Inside the container:

```bash
ros2 pkg list | grep -E 'bridge_interfaces|bridge|robot|sensors|vision'
ros2 interface show bridge_interfaces/msg/SystemPower
ros2 interface show bridge_interfaces/msg/DCStateAll
ros2 interface show bridge_interfaces/srv/SetFirmwareState
```

Expected result:

- all five package names appear
- the message and service definitions print correctly

### 9. Start the Bridge Node First

In the first container shell:

```bash
ros2 run bridge bridge
```

Expected result:

- the node starts without crashing
- in real hardware mode, the bridge connects to `/dev/ttyAMA0`
- in mock mode, the bridge reports mock operation

Open a second shell and verify:

```bash
./ros2_ws/docker/enter_ros2.sh rpi
ros2 node list
ros2 topic list
ros2 service list | grep set_firmware_state
ros2 topic echo /sys_state
```

You can also verify the web bridge from the host:

```bash
curl http://localhost:8000/health
```

### 10. Start Other Nodes One by One

Example robot node:

```bash
./ros2_ws/docker/enter_ros2.sh rpi
ros2 run robot robot
```

The `robot` node is the main student application layer. Students only edit
`src/robot/robot/main.py`. See
[`src/robot/README.md`](src/robot/README.md) for the API reference.

The `sensors` and `vision` packages can be started the same way when needed.

## Daily Workflow

### Re-enter the Container

```bash
./ros2_ws/docker/enter_ros2.sh rpi
```

or:

```bash
./ros2_ws/docker/enter_ros2.sh vm
```

This is the normal way to get back into `/ros2_ws` with ROS sourced correctly.

### Restart a Node After Code Changes

If the container is already running and you changed only Python code, usually
you only need to stop the old process and run it again:

```bash
ros2 run bridge bridge
ros2 run robot robot
```

Use `Ctrl+C` to stop a foreground node before restarting it.

## Do I Need `colcon build` After Updates?

Not always.

### Usually no rebuild needed

If you changed only Python source and the workspace was built with
`--symlink-install`, restarting the affected node is usually enough.

Typical examples:

- `ros2_ws/src/bridge/bridge/*.py`
- `ros2_ws/src/robot/robot/*.py`

### Rebuild required

You should rebuild the ROS workspace when you change:

- `.msg` or `.srv` files
- `package.xml`
- `CMakeLists.txt`
- package entry points or install metadata
- anything that generates code or alters the install tree

Examples:

- adding a new message in `bridge_interfaces/msg`
- changing `bridge_interfaces/CMakeLists.txt`
- seeing import errors for a new message that exists in `src/` but not in `install/`

### Safe rule of thumb

- Python-only change: try restarting the node first
- message/service/build-file change: rebuild
- if the running behavior still looks old: rebuild anyway

## Rebuild and Rerun the Entrypoint

### Rerun the entrypoint and reuse the cached ROS build

Use this after normal source edits when the Docker image itself did not change.

```bash
docker compose -f $COMPOSE restart ros2_runtime
docker compose -f $COMPOSE logs -f ros2_runtime
```

This restarts the container, reruns `/entrypoint.sh`, and runs `colcon build`
again against the existing cached `build/` and `install/` volumes.

### Rebuild the Image and Then Rerun the Entrypoint

Use this after Dockerfile, apt, pip, or system dependency changes.

```bash
docker compose -f $COMPOSE build ros2_runtime
docker compose -f $COMPOSE up -d --force-recreate ros2_runtime
docker compose -f $COMPOSE logs -f ros2_runtime
```

### Force a Clean ROS Workspace Rebuild

Use this when generated interfaces changed or the installed ROS artifacts look
stale.

```bash
docker compose -f $COMPOSE down -v
docker compose -f $COMPOSE up -d --build
docker compose -f $COMPOSE logs -f ros2_runtime
```

## Useful Commands

```bash
# Stop the running container
docker compose -f $COMPOSE down

# Stop and also clear the ROS build/install cache
docker compose -f $COMPOSE down -v

# Rebuild the Docker image
docker compose -f $COMPOSE build

# View logs from the background container
docker compose -f $COMPOSE logs -f ros2_runtime
```

## Firmware State and Topic Checks

Once the bridge is running and `/sys_state` shows `IDLE`, you can test the
firmware state service:

```bash
ros2 service call /set_firmware_state bridge_interfaces/srv/SetFirmwareState "{target_state: 2}"
ros2 service call /set_firmware_state bridge_interfaces/srv/SetFirmwareState "{target_state: 1}"
```

Continuous motor control remains topic-based:

```bash
ros2 service call /set_firmware_state bridge_interfaces/srv/SetFirmwareState "{target_state: 2}"
ros2 topic pub --once /dc_set_velocity bridge_interfaces/msg/DCSetVelocity \
  "{motor_number: 1, target_ticks: 200}"
```

## Native Ubuntu 24.04 Workflow

Native ROS2 is optional. If you are on Ubuntu 24.04, you can build the
workspace without Docker after installing ROS2 Jazzy.

```bash
cd ros2_ws
source /opt/ros/jazzy/setup.bash
colcon build --symlink-install
source install/setup.bash
```

The shared backend source must also be available on `PYTHONPATH` or pointed to
with `NUEVO_BRIDGE_SOURCE`:

```bash
export NUEVO_BRIDGE_SOURCE="$(pwd)/../nuevo_ui/backend"
ros2 run bridge bridge
```

## Beginner Notes

- `bridge_interfaces` is the raw firmware and bridge-facing interface package. It is not a node.
- `bridge` is the ROS package that starts the integrated UI + ROS bridge.
- `nuevo_bridge` is the shared Python runtime outside `ros2_ws`.
- `robot` is the main student application layer. It wraps the bridge API and is where FSM logic lives.
- `sensors` and `vision` are separate packages for future hardware expansion and are currently scaffolds.
- discrete operations such as firmware state changes should use services
- continuous commands such as velocity or PWM should stay on topics

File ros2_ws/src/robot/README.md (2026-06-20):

# Robot Package

High-level autonomy for MARSY: the Robot API, FSMs, planners, perception integration, and the demo programs that run the full graded course and the precision pick-and-place.

This package sits on top of the provided ROS 2 bridge (TLV ⇆ ROS) and below the sensor nodes that feed it. The team's contribution here is the [`programs/`](robot/programs/) tree, the manipulator FSM and inverse kinematics, the lane-switch avoidance customization, and the cup-pair vision logic. The `Robot` class itself and the path-planner scaffolding came from the teaching team and were extended for the venue.

---

## Layout

| Path | What it is |
|---|---|
| [`robot.py`](robot/robot.py) | The `Robot` class. Composes four mixins, owns ROS publishers/subscriptions, exposes the public API. |
| [`robot_impl/`](robot/robot_impl/) | The four mixin modules: `hardware.py` (motor/servo/stepper/LED), `sensors.py` (cached state from the spin thread), `navigation.py` (alternative planner integrations), `legacy.py` (the shipped venue-demo planner path). |
| [`path_planner.py`](robot/path_planner.py) | Path-planning algorithm classes. See Planners below. |
| [`arm_kinematics.py`](robot/arm_kinematics.py) | Closed-form 3-DOF inverse kinematics with explicit elbow-up branch selection. |
| [`hardware_map.py`](robot/hardware_map.py) | Pin mapping, motor IDs, LED/button enums, default rates. |
| [`_manipulator_config.py`](robot/_manipulator_config.py) | Manipulator geometry, joint limits, calibration constants. |
| [`sensor_fusion.py`](robot/sensor_fusion.py) | Complementary filters for heading and position. |
| [`obstacle_tracking.py`](robot/obstacle_tracking.py) | LiDAR cluster tracking that feeds the avoidance planner. |
| [`programs/`](robot/programs/) | All runnable hardware programs. See [`programs/README.md`](robot/programs/README.md). |
| [`examples/`](robot/examples/) | Smaller reference snippets for individual API areas. |
| [`robot_node.py`](robot/robot_node.py) | ROS node entry point. Builds a `Robot`, calls `main.run(robot)`. |
| [`main.py`](robot/main.py) | Selects which program runs by import. |

---

## Execution model

```
sensor ROS nodes (vision, LiDAR, GPS/ArUco, ultrasonic)
        │
        ▼
Robot class (robot.py + four mixins)
        │
        ▼
bridge node (TLV ⇆ ROS) ⇆ Arduino firmware over UART
```

The ROS spin thread continuously refreshes cached state from sensor topics. The active program runs an explicit FSM loop and issues commands through the Robot API. Path-following methods spin their own nav thread that calls planner `compute_velocity()` and writes drive commands.

Path planners are pure algorithm classes. They do not own ROS subscriptions or threads.

---

## Planners

The shipped venue demo ([`programs/demos/full_competition_venue_run.py`](robot/programs/demos/full_competition_venue_run.py)) uses **`PurePursuitPlannerWithAvoidance`** in [`path_planner.py`](robot/path_planner.py), invoked via [`robot_impl/legacy.py`](robot/robot_impl/legacy.py)'s `_nav_follow_pp_path`. When a cone is detected, the planner inserts a hat-shaped detour into the remaining waypoint list: lane offset on entry, hold past obstacle, return to center on exit.

The other planners in `path_planner.py` (`APFPlanner`, `LeashedAPFPlanner`, base `PurePursuitPlanner`) are alternative implementations explored during development but **not used in the final demo**. They remain in the tree as reference.

---

## Entry points

Two headline programs:

- [`programs/demos/full_competition_venue_run.py`](robot/programs/demos/full_competition_venue_run.py) for the full graded venue course
- [`programs/demos/precision_stack_manipulator_demo.py`](robot/programs/demos/precision_stack_manipulator_demo.py) for vision-driven pick-and-place

Select which one runs by uncommenting exactly one import in [`main.py`](robot/main.py).

---

## API conventions

- **Units**: lengths and velocities use the active `Unit` (set via `robot.set_unit(Unit.MM)` or `Unit.INCH`). Method names ending in `_mm` are always raw millimeters regardless of the active unit.
- **Angles**: heading is degrees in the public API. The one exception is `max_angular_rad_s` in path-following calls, which is rad/s.
- **Motion**: high-level motion calls return a `MotionHandle` and accept `blocking=True` (the default) or `blocking=False` (returns immediately; poll with `handle.is_finished()`). Only one high-level motion runs at a time.

Source of truth for all method signatures: [`robot.py`](robot/robot.py).

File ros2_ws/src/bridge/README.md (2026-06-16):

# bridge

ROS2 wrapper package around the shared nuevo_bridge runtime.

## Overview

The bridge package mediates between the ROS2 graph and the Arduino firmware
over a serial connection. It translates ROS2 messages from `bridge_interfaces`
into firmware commands, and relays firmware state and sensor telemetry back
into the ROS2 ecosystem.

## Nodes / Entrypoints

- `bridge_node` — main bridge node; manages the serial connection lifecycle
- `ros_controller` — maps ROS2 command topics to firmware calls
- `ros_conversions` — helpers for converting between ROS2 and firmware types
- `firmware_state_service` — exposes a service for querying firmware state

## Launch

```bash
ros2 launch bridge bridge.launch.py
```

## Dependencies

- `rclpy`
- `std_msgs`
- `builtin_interfaces`
- `bridge_interfaces`

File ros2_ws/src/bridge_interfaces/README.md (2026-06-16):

# bridge_interfaces

Custom ROS2 interfaces for the raw firmware and bridge boundary.

## Overview

This ament_cmake package defines the message and service types shared across
packages that communicate through the bridge layer (DC motors, servos, steppers,
IMU, LiDAR, vision detections, system state, etc.).

## Messages (`msg/`)

Covers motor control (DC, servo, stepper), IO (LED, Neopixel), sensor
telemetry (IMU, kinematics, magnetometer), vision (tag detections, obstacle
tracking), and system management (config, diagnostics, power, state).

Key message families:
- `DC*` — DC motor commands and state
- `Servo*` / `Step*` — servo and stepper motor commands and state
- `Sensor*` — IMU, kinematics, magnetometer calibration
- `System*` / `Sys*` — system config, diagnostics, odometry
- `Tag*` / `Vision*` / `Tracked*` — vision pipeline outputs

## Services (`srv/`)

- `SetFirmwareState` — set the active firmware operating state

## Dependencies

- `std_msgs`
- `builtin_interfaces`

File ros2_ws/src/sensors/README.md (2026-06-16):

# sensors

ROS2 package for Raspberry Pi connected sensors outside the Arduino firmware.

## Overview

This package hosts ROS2 nodes for sensors that connect directly to the onboard
Raspberry Pi rather than going through the Arduino firmware/bridge layer.
Sensor data is published using message types from `bridge_interfaces`.

## Nodes

- `sensor_node` — base sensor abstraction
- `robot_gps_node` — GPS integration node
- `qwiic_ultrasonic_node` — SparkFun Qwiic ultrasonic distance sensor
- `mock_lidar_node` — software mock of LiDAR output for testing

## Launch

```bash
ros2 launch sensors sensors.launch.py
```

## Dependencies

- `rclpy`
- `bridge_interfaces`
- `sensor_msgs`

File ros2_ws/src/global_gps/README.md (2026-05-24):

# Global GPS — Field Localizer

Runs on the **Jetson Nano** (not on the robot RPis).

Uses a RealSense D4xx camera (overhead or tripod-mounted at an oblique angle —
see "Non-coplanar tags and the ground plane" below) to detect ArUco markers and
publish 2-D world-frame positions for all rover robots simultaneously.

## How it works

1. **Calibration**: On startup, the node waits until all four corner anchor
   markers (IDs 0–3 by default) are visible at once. It then SVD-aligns the
   four measured tag tvecs to the **known world-frame coordinates** that you
   provided in `config/calibration_layout.yaml` (Kabsch / Umeyama with a
   reflection guard). The ground plane in camera frame is derived
   analytically as the image of the world `z = 0` plane. Calibration is
   automatic — just make sure the camera can see all four corners when the
   node starts. The most recent successful transform is cached to
   `/runtime_output/global_gps/transform_cache.yaml` by default; if startup
   cannot find enough localization markers within 30 seconds, the node logs a
   warning and falls back to that cached transform.

2. **Tracking**: Once calibrated, the node detects any rover markers (IDs 11–18
   by default) in every frame and publishes their 2-D poses (x, y, theta) on
   `/global_gps/tag_detections` across the network.

3. **Robot side**: Each robot runs a `robot_gps` node (in the `sensors` package)
   that subscribes to the Jetson's global topic and re-publishes detections
   locally so the robot's main node can use them.

## Marker setup

| Role | IDs | Size |
|---|---|---|
| Field corner anchors | 0, 1, 2, 3 | configurable (`marker_size` param) |
| Rover markers | 11–18 | same size |

Place corner markers at the four corners of the field with the **same physical
size** as the rover markers. The world frame origin, axes, and units are
defined entirely by what you write in `config/calibration_layout.yaml` — see
the next section.

## Tripod / oblique camera mounts

The localizer works whether the RealSense is hung directly overhead or
mounted on a **tripod looking down at an angle**. In the tripod case the
ground plane is no longer trivially perpendicular to the camera, so the node
recovers the world frame by SVD-aligning the four detected corner-tag
positions to a layout you supply.

### Filling in `calibration_layout.yaml`

The packaged default lives at
`ros2_ws/src/global_gps/config/calibration_layout.yaml`:

```yaml
# All values in metres. z = 0 because the four tags lie on the ground.
calibration_tags:
  0: [0.000, 0.000, 0.0]
  1: [2.400, 0.000, 0.0]
  2: [0.000, 1.800, 0.0]
  3: [2.400, 1.800, 0.0]
```

Steps:

1. Put down corner markers 0, 1, 2, 3 anywhere you like on the ground.
2. Pick a world-frame convention. A typical choice: tag 0 at the origin,
   `+X` toward tag 1, `+Y` toward tag 2.
3. Measure the inter-tag distances by hand (tape measure) and fill in the
   `(x, y, 0)` triple for each tag in your chosen frame.
4. Either edit the packaged file directly, or write your own and pass
   `calibration_layout_file:=/path/to/your.yaml` to the launch.

Whatever convention you pick is what downstream rover poses are reported in.

### Non-coplanar tags and the ground plane

Calibration tags do **not** have to be coplanar with the floor — any
known `(x, y, z)` layout works, and a layout where the four tags sit at
visibly different heights (e.g. two on the floor, two on short stands)
is in fact better-conditioned than a flat one because the depth axis is
constrained directly. Because the tags can now sit anywhere in 3-D, the
ground plane is specified independently in the world frame via an
optional `ground_plane` block in `calibration_layout.yaml`:

```yaml
ground_plane:
  point:  [0.0, 0.0, 0.0]
  normal: [0.0, 0.0, 1.0]
```

If the block is omitted, the default is `point=(0,0,0)`,
`normal=(0,0,1)` — i.e. world `z = 0`, which preserves prior behaviour
for users whose tags lie flat on the floor. Rover tag tvecs are
projected onto this plane before being reported as `(x, y)` detections.

### RGB-only operation

The localizer subscribes only to `/camera/camera/color/image_raw`. The
RealSense depth stream is **no longer consumed** by this node — all
geometry is recovered from the calibrated camera pose plus the
configured ground plane. Other nodes that consume depth are unaffected.

### Reading the calibration log line

When calibration succeeds the node logs something like:

```
Calibration complete. Residuals max=4.1mm rms=2.7mm per-tag=[0:1.2mm, 1:3.8mm, 2:4.1mm, 3:2.0mm]
```

`max` is the worst per-tag fit error (Euclidean distance between the
measured tvec and the SVD-predicted tvec). Rule of thumb:

- **`max < 10 mm` (1 cm)** — healthy. Use as is.
- 1–3 cm — usable but suspect; re-measure inter-tag distances or check that
  the camera's intrinsic calibration is reasonable.
- `> 3 cm` — bad. Likely causes: typo in the YAML, mis-placed corner
  marker, very oblique tripod angle that pushes per-tag depth noise up, or
  one of the four tags partially occluded.

## ROS topic

| Topic | Type | Publisher |
|---|---|---|
| `/global_gps/tag_detections` | `bridge_interfaces/TagDetectionArray` | Jetson |
| `/tag_detections` | `bridge_interfaces/TagDetectionArray` | `robot_gps` (RPi) |

Each `TagDetection` in the array contains:

```
int32   tag_id   # ArUco marker ID
float32 x        # world-frame X (metres)
float32 y        # world-frame Y (metres)
float32 theta    # heading (radians, CCW from world X)
```

---

## Jetson setup

### Prerequisites (one-time, on the Jetson host)

1. **JetPack 6.x** (Ubuntu 22.04) installed and working.
2. **Docker** installed:
   ```bash
   curl -fsSL https://get.docker.com -o get-docker.sh
   sudo sh get-docker.sh
   # JetPack may not create the docker group automatically — create it if missing:
   sudo groupadd docker 2>/dev/null || true
   sudo usermod -aG docker $USER
   newgrp docker
   docker --version
   ```
3. Clone your fork of the repository:
   ```bash
   git clone https://github.com/<your-username>/Project-NUEVO.git
   cd Project-NUEVO
   ```

### Build and start the container

```bash
COMPOSE=ros2_ws/docker/docker-compose.jetson.yml

docker compose -f $COMPOSE build       # first time only (~5 min)
docker compose -f $COMPOSE up -d
docker compose -f $COMPOSE logs -f global_gps   # watch colcon build
```

Wait until the log shows `[entrypoint] Container ready`.

### Launch the localizer

```bash
docker compose -f $COMPOSE exec global_gps bash
source /opt/ros/jazzy/setup.bash
source /ros2_ws/install/setup.bash
ros2 launch global_gps global_gps.launch.py
```

To override default parameters:

```bash
ros2 launch global_gps global_gps.launch.py \
    marker_size:=0.15 \
    corner_ids:=[0,1,2,3] \
    rover_ids:=[11,12,13]
```

The cache fallback can be configured explicitly:

```bash
ros2 launch global_gps global_gps.launch.py \
    transform_cache_file:=/runtime_output/global_gps/transform_cache.yaml \
    startup_cache_timeout_sec:=30.0
```

### Boot-time startup service

This package now includes host-side startup assets:

- `scripts/start_global_gps_stack.sh`
- `systemd/global-gps-stack.service`

The service template does the two required startup actions:

1. `docker compose ... up -d --wait global_gps`
2. `ros2 launch global_gps global_gps.launch.py`

Because enabling `systemd` on the Jetson modifies host state outside
`src/global_gps`, installation is still a manual host step. Copy or symlink
the packaged `systemd/global-gps-stack.service` into `/etc/systemd/system/`,
adjust `WorkingDirectory` if the repo lives elsewhere, then run:

```bash
sudo systemctl daemon-reload
sudo systemctl enable --now global-gps-stack.service
```

### Capture a photo of the camera's field of view

A standalone script is included that saves a single JPEG from the RealSense
camera without needing the full ROS2 stack running.  It uses `pyrealsense2`
directly via the libusb/V4L2 backend and automatically repairs missing device
nodes inside the container after a USB re-enumeration.

**One-time setup** — install `pyrealsense2` inside the container:
```bash
docker compose -f $COMPOSE exec global_gps \
    pip3 install --break-system-packages pyrealsense2
```

**Capture a photo** (saves to `/tmp/gps_snapshot_<timestamp>.jpg` by default):
```bash
# From the Jetson host:
docker exec docker-global_gps-1 \
    python3 /ros2_ws/src/global_gps/capture_photo.py

# Or from inside the container shell:
python3 /ros2_ws/src/global_gps/capture_photo.py

# Custom output path:
python3 /ros2_ws/src/global_gps/capture_photo.py --output /tmp/field.jpg
```

The script waits for 15 warm-up frames (~0.5 s) so auto-exposure settles
before saving.  Additional options:

```
--output / -o   Output file path
--warmup        Warm-up frame count (default: 15)
--width         Stream width  (default: 640)
--height        Stream height (default: 480)
--fps           Stream FPS    (default: 30)
```

> **Note:** The GPS launch (`ros2 launch global_gps global_gps.launch.py`)
> must **not** be running when you capture a photo — both the launch and the
> script compete for exclusive camera access.  Stop the launch first, capture,
> then restart it if needed.

### Verify detections from any machine on the network

```bash
# Quick test: connect to the Jetson TCP server directly (no ROS needed)
# nc -v 192.168.8.120 7777   # should show JSON lines when markers are visible

# Or from inside the robot container:
ros2 topic echo /tag_detections
```

---

## Robot-side setup (RPi per robot)

The `robot_gps` node in the `sensors` package bridges the Jetson's global
topic into the robot's local domain.

### Start robot_gps

Open a terminal inside the robot's container and run it separately from
the bridge/robot nodes:

```bash
COMPOSE=ros2_ws/docker/docker-compose.rpi.yml

docker compose -f $COMPOSE exec ros2_runtime bash
source /opt/ros/jazzy/setup.bash
source /ros2_ws/install/setup.bash
ros2 run sensors robot_gps
```

No special environment variables are needed.  The node connects to the
Jetson's TCP server directly, which works through the lab WiFi NAT.

Once running, the topic `/tag_detections` becomes available locally and other
nodes (robot node, etc.) can subscribe to it with the RPi Docker default
`ROS_AUTOMATIC_DISCOVERY_RANGE=LOCALHOST`.

### Subscribe in the robot node

```python
from bridge_interfaces.msg import TagDetectionArray

self.create_subscription(
    TagDetectionArray,
    "/tag_detections",
    self._on_gps_update,
    10,
)

def _on_gps_update(self, msg: TagDetectionArray) -> None:
    for det in msg.detections:
        print(f"Robot {det.tag_id}: ({det.x:.2f}, {det.y:.2f})")
```

---

## Troubleshooting

**No detections published / calibration never completes**
- Make sure all four corner marker IDs (default 0–3) are visible in the camera
  frame simultaneously when the node starts.
- Check that `corner_ids` and `rover_ids` parameters match the printed markers.

**RealSense camera not found**
- Confirm the camera is connected: `rs-enumerate-devices` (inside the container).
- The container runs with `privileged: true` which is required for the
  librealsense2 USB driver. If the camera still isn't found, try
  `docker compose down` and `up -d` with the camera already plugged in.

**Robot cannot see `/tag_detections`**
- Confirm `robot_gps` is running in the RPi container.
- Confirm the Jetson and the RPi are on the same network.
- Confirm the Jetson TCP server is reachable from the RPi:
  `nc -v 192.168.8.120 7777`
- From the RPi container: `ros2 topic echo /tag_detections` should show data
  when rover markers are visible.

**Multiple `/bridge` nodes visible**
- See [`docs/ros2/troubleshooting.md`](../../../docs/ros2/troubleshooting.md).

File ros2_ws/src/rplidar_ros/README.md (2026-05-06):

# RPLidar C1 Driver

This package is the Project NUEVO ROS 2 driver for the Slamtec RPLidar C1.

It keeps the vendor Slamtec SDK in `sdk/`, but the ROS wrapper is intentionally
C1-only and small. Higher-level interpretation of `/scan` belongs in the
`sensors` package.

## Quick Start

Run the host setup once on the native Raspberry Pi Ubuntu host:

```bash
./ros2_ws/src/rplidar_ros/scripts/install_udev_rule.sh
```

Unplug and reconnect the RPLidar C1, then verify the stable device path:

```bash
ls -l /dev/rplidar
```

If you need to remove the host rule later:

```bash
./ros2_ws/src/rplidar_ros/scripts/uninstall_udev_rule.sh
```

Start the driver inside the ROS container:

```bash
docker compose -f ros2_ws/docker/docker-compose.rpi.yml exec ros2_runtime bash -lc \
  'source /ros2_ws/install/setup.bash && ros2 launch rplidar_ros rplidar_c1.launch.py'
```

In another shell, take one scan sample:

```bash
docker compose -f ros2_ws/docker/docker-compose.rpi.yml exec ros2_runtime bash -lc \
  'source /ros2_ws/install/setup.bash && ros2 topic echo /scan --once'
```

## Runtime Behavior

The node publishes:

```text
scan  sensor_msgs/msg/LaserScan
```

Defaults:

```text
serial_port       /dev/rplidar
serial_baudrate   460800
frame_id          laser
topic_name        scan
scan_mode         Standard
scan_frequency    10.0
range_min         0.05
range_max         12.0
angle_compensate  true
```

If `/dev/rplidar` is missing, the node stays alive and retries. This keeps the
Docker container and launch file healthy when the lidar is optional or unplugged.

## Launch Manually

```bash
ros2 launch rplidar_ros rplidar_c1.launch.py
```

Override the device path if needed:

```bash
ros2 launch rplidar_ros rplidar_c1.launch.py serial_port:=/dev/ttyUSB0
```

## Udev Rule

The preferred device path is `/dev/rplidar`.

Install the included udev rule on the Raspberry Pi host:

```bash
./ros2_ws/src/rplidar_ros/scripts/install_udev_rule.sh
```

Unplug and reconnect the lidar, then verify:

```bash
ls -l /dev/rplidar
```

Remove the rule if you want to undo the host setup:

```bash
./ros2_ws/src/rplidar_ros/scripts/uninstall_udev_rule.sh
```

The rule uses the common CP210x USB serial adapter IDs:

```text
idVendor=10c4
idProduct=ea60
```

## Sanity Checks

Inside the ROS container:

```bash
source /ros2_ws/install/setup.bash
ros2 launch rplidar_ros rplidar_c1.launch.py
```

In another shell:

```bash
source /ros2_ws/install/setup.bash
ros2 node list | grep /rplidar_c1
ros2 topic echo /scan --once
```

## Code Ownership

This package should stay focused on hardware I/O and standard `LaserScan`
publishing. Do not add obstacle detection, global-coordinate transforms, or
robot-pose fusion here.

The intended layering is:

```text
rplidar_ros
  /scan in laser frame

sensors
  /scan + robot pose + lidar mounting transform
  -> robot/world obstacle data
```

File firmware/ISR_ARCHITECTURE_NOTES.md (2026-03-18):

# ISR Architecture Notes (UART @ 500 kbps)

This document summarizes the final ISR design for reliable UART RX while keeping
hard real-time tasks deterministic. It reflects both the original findings at 1 Mbps
and the validated architecture after relaxing to 500 kbps.

## Findings (Original State at 1 Mbps)

- At 1 Mbps, the AVR UART can only tolerate ~20 µs of interrupt-off time
  (roughly two byte times). Anything longer risks `DOR2` (overrun).
- Dropped bytes show up as:
  - `DOR2` increments (overrun) when the UART RX ISR can't run in time.
  - CRC errors in TLV decode (payload corruption).
- Adding `sei()` inside ISRs was tested and does not fix the problem — it shifts
  overruns to other tasks because nested interrupts create unpredictable timing.
- At 500 kbps (8N1): byte every 20 µs, 2-byte HW FIFO → `USART2_RX_vect` must
  fire within **40 µs**. This doubles the ISR budget and makes the architecture
  viable without any `sei()`.

## Constraints on ATmega2560

- No configurable interrupt priorities. There is only global enable/disable.
- Nested interrupts are possible by calling `sei()` inside an ISR, but create
  unpredictable timing and were explicitly rejected.
- Worst-case ISR pile-up at 500 kbps: TIMER3 (~3 µs) + TIMER1 (~15 µs) +
  TIMER0/millis (~5 µs) = **~23 µs** — well inside the 40 µs budget.

## Final Architecture

### Layer 1: Hard Real-Time ISRs (short, no `sei()`)

```
USART2_RX_vect     per-byte     ~2 µs
  - Provided by Arduino core (HardwareSerial).
  - Pushes bytes into the 1024-byte HardwareSerial ring buffer.
  - Not replaced; all other ISRs must stay short enough to not block it.

TIMER3_OVF_vect    10 kHz       <5 µs
  - Stepper step pulses only (direct PORTx writes — no digitalWrite).
  - Precompute step intervals in loop; ISR decrements counter, pulses STEP pin.
  - Remove delayMicroseconds(2); use 8× nop for ~500 ns STEP pulse width.

TIMER1_OVF_vect    800 Hz       <20 µs
  - Full fixed-point round-robin PID: 1 motor per tick = 200 Hz per motor.
  - Uses Q16.16 fixed-point, constant dt, no ADC, no prints, no micros().
  - Direct OCR register writes for PWM (no analogWrite/digitalWrite).
  - Velocity estimate precomputed in loop and latched into a volatile Q16.16.

ENCODER ISRs       edge-triggered   ~1–2 µs
  - Edge counting only (INT0/INT1/INT4/INT5).
```

Key rule: no ISR may call `sei()`. Each ISR must exit before the next byte
arrives (every 20 µs at 500 kbps). The 40 µs tolerance means even back-to-back
TIMER3 + TIMER1 firings leave safe margin.

### Layer 2: Loop Tasks via Scheduler (millis-based, preemptible)

```cpp
loop() {
    // 1. Highest priority: drain Serial2 into TLV decoder
    while (Serial2.available()) {
        uint8_t b = (uint8_t)Serial2.read();
        decodePacket(&decodeDesc_, &b);
    }

    // 2. Run one scheduled task per iteration
    Scheduler::tick();
}
```

Scheduled tasks:
| Task | Rate | Work |
|---|---|---|
| UART telemetry TX | 100 Hz | `MessageCenter::sendTelemetry()` |
| Heartbeat timeout check | 100 Hz | `MessageCenter::checkHeartbeatTimeout()` |
| Sensor I2C reads | 100 / 50 / 10 Hz | IMU, lidar, ultrasonic |
| Buttons + safety | 100 Hz | UserIO, SafetyManager |
| UserIO / LEDs | 20 Hz | NeoPixel, status LED |
| **Debug print flush** | 10 Hz | `taskDebugFlush()` — see below |

### Layer 3: Debug Print Buffer (non-blocking)

Direct `DEBUG_SERIAL.print()` calls block for up to ~7 ms (80 chars at 115200 baud),
creating long loop() gaps that delay Serial2 draining. Replace all debug prints with
a ring buffer and a non-blocking flush task:

```cpp
// ---- DebugLog (simple inline ring buffer) ----

#define DBG_BUF_SIZE 512

static char     dbgBuf_[DBG_BUF_SIZE];
static uint16_t dbgHead_ = 0;
static uint16_t dbgTail_ = 0;

// Call only from loop() / Scheduler context (not ISR-safe)
inline void dbgPrint(const char *str) {
    while (*str) {
        uint16_t next = (dbgTail_ + 1) % DBG_BUF_SIZE;
        if (next == dbgHead_) return;  // buffer full — drop
        dbgBuf_[dbgTail_] = *str++;
        dbgTail_ = next;
    }
}

// Scheduler task @ 10 Hz — non-blocking, outputs only what the TX buffer can absorb
void taskDebugFlush() {
    int avail = DEBUG_SERIAL.availableForWrite();
    while (avail > 0 && dbgHead_ != dbgTail_) {
        DEBUG_SERIAL.write(dbgBuf_[dbgHead_]);
        dbgHead_ = (dbgHead_ + 1) % DBG_BUF_SIZE;
        avail--;
    }
}
```

At 115200 baud, `taskDebugFlush` at 10 Hz passes up to 64 bytes/call (the USB TX
buffer size) → 640 bytes/sec throughput. This is enough for all status output
without ever blocking loop().

## Confirmed Decisions

- **Baud rate: 500 kbps** (relaxed from 1 Mbps to double the ISR budget to 40 µs).
- Do not replace `USART2_RX_vect`. It already exists in Arduino core.
- **All ISRs < 20 µs body time, no `sei()` anywhere.**
- `SERIAL_RX_BUFFER_SIZE = 1024` (via `-DSERIAL_RX_BUFFER_SIZE=1024` compiler flag).
  At 500 kbps the buffer fills in ~20 ms — loop drain is easily fast enough.
- Stepper ISR uses direct port writes; no `delayMicroseconds()` or `digitalWrite()`.
- **Full fixed-point PID in TIMER1 ISR** (viable at 500 kbps budget).
- **Serial2 drained continuously in loop()** — not in any ISR.
- TLV decode (`decodePacket`) runs in loop(), called directly from the drain loop.
- Decode callback (`decodeCallback`) only updates variables — no I2C, no prints.
- Sensor I2C reads move to Scheduler tasks; TIMER4 removed entirely.
- All debug output goes through `dbgPrint()` → ring buffer → `taskDebugFlush()`.

## ISR Budget Summary

| ISR | Frequency | Estimated body | Total (with overhead) | Budget |
|-----|---|---|---|---|
| USART2_RX_vect | per-byte | ~1 µs | ~2 µs | — |
| TIMER3_OVF | 10 kHz | ~1–2 µs | ~4 µs | < 40 µs |
| TIMER1_OVF | 800 Hz | ~10–15 µs | ~17 µs | < 40 µs |
| TIMER0_OVF (millis) | ~977 Hz | ~3 µs | ~5 µs | unavoidable |
| Worst-case pile-up | — | — | TIMER3 + TIMER1 + TIMER0 ≈ 26 µs | ✓ |

## Fixed-Point PID Structure (TIMER1 ISR)

```cpp
// Q16.16 fixed-point. All gains precomputed in setup()/loop().
struct PIDFx {
    int32_t kp;      // Q16.16
    int32_t ki_dt;   // ki × dt, precomputed
    int32_t kd_div_dt; // kd / dt, precomputed
    int32_t i_acc;   // integrator accumulator, Q16.16
    int32_t e_prev;  // previous error, Q16.16
};

inline int16_t pid_step(PIDFx& p, int32_t e_q16,
                        int16_t out_min, int16_t out_max) {
    p.i_acc += ((int64_t)p.ki_dt * e_q16) >> 16;
    if (p.i_acc > ((int32_t)out_max << 16)) p.i_acc = ((int32_t)out_max << 16);
    if (p.i_acc < ((int32_t)out_min << 16)) p.i_acc = ((int32_t)out_min << 16);

    int32_t p_term = ((int64_t)p.kp       * e_q16)             >> 16;
    int32_t d_term = ((int64_t)p.kd_div_dt * (e_q16 - p.e_prev)) >> 16;
    p.e_prev = e_q16;

    int32_t out = p_term + p.i_acc + d_term;
    if (out > ((int32_t)out_max << 16)) out = ((int32_t)out_max << 16);
    if (out < ((int32_t)out_min << 16)) out = ((int32_t)out_min << 16);
    return (int16_t)(out >> 16);
}

ISR(TIMER1_OVF_vect) {
    static uint8_t motor = 0;  // round-robin 0..3
    int32_t pos    = enc[motor].getCount();          // atomic volatile read
    int32_t vel    = velEstQ16[motor];               // latched from loop
    int32_t e_q16  = (targetVel[motor] - vel);       // or position error
    int16_t pwm    = pid_step(pid[motor], e_q16, -255, 255);
    setPWM_fast(motor, pwm);   // direct OCRnx write
    motor = (motor + 1) & 0x03;
    // NO sei()
}
```

## Changes from Previous Architecture

| What | Before | After |
|---|---|---|
| UART baud | 1 Mbps | **500 kbps** |
| ISR budget | 20 µs | **40 µs** |
| UART drain | TIMER3 ISR at 10 kHz | **loop() continuous drain** |
| PID | TIMER1 ISR, float, 4 motors/tick, ~200 µs | **TIMER1 ISR, Q16.16, 1 motor/tick, <17 µs** |
| Stepper | TIMER3 with digitalWrite | **TIMER3 with direct port writes** |
| Sensor I2C | TIMER4 ISR with sei() | **Scheduler tasks (no ISR)** |
| TLV decode | TIMER4 ISR | **loop() immediately after drain** |
| TLV TX | TIMER4 ISR | **Scheduler task @ 100 Hz** |
| TIMER4 | Sensor + UART decode/TX | **Removed entirely** |
| Debug prints | Blocking DEBUG_SERIAL.print() | **Ring buffer + taskDebugFlush @ 10 Hz** |

## Implementation Order

1. **Implement and validate `test_uart_loop_drain`** (done — zero DOR2 at 500 kbps confirmed).

2. **Main firmware changes**:
   - Set `RPI_BAUD_RATE = 500000` in `config.h` (done).
   - Add `-DSERIAL_RX_BUFFER_SIZE=1024` compiler flag.
   - Strip TIMER1 to fixed-point round-robin PID only.
   - Strip TIMER3 to stepper port-writes only; remove `drainUart()`.
   - Remove TIMER4 ISR entirely.
   - Move decode + drain to top of `loop()`.
   - Move sensors, buttons, safety, TX to `Scheduler::tick()`.
   - Replace all `DEBUG_SERIAL.print()` with `dbgPrint()` + `taskDebugFlush`.

3. **Validate**:
   - `DOR2 == 0` sustained at 500 kbps.
   - PID control quality (step response, position hold) acceptable.
   - Stepper motion smooth.
   - LoopMonitor reports all slots within budget.

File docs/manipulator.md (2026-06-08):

# NUEVO Manipulator Reference

Working notes for the 3-DOF pick/place arm — geometry, IK conventions, joint
limits, hardware-collision envelope, ranging pose, and the place coordinate
that the competition demo uses.

The numbers here mirror `_manipulator_config.py`.  Keep both in sync when
you recalibrate.

---

## 1. Arm geometry

| Constant | Value | Notes |
|---|---|---|
| `ARM_L1_MM` | 156 mm | upper arm: shoulder pivot → elbow pivot |
| `ARM_L2_MM` | 315 mm | forearm: elbow pivot → gripper end |
| `ARM_SHOULDER_HEIGHT_MM` | 95 mm | shoulder pivot above base plate (z=0) |
| `ARM_SHOULDER_OFFSET_MM` | 14 mm | shoulder pivot forward of turntable axis |
| Max reach from shoulder | 471 mm | `L1 + L2` |
| Max horizontal reach from turntable axis | ~485 mm at shoulder height |

The shoulder pivot orbits the turntable axis at 14 mm radius — accounted for
inside `forward_kinematics` and `inverse_kinematics` automatically.

## 2. Chassis / base plate / sensor envelope

| Constant | Value | Notes |
|---|---|---|
| `BASE_PLATE_SIZE_MM` | 279.4 mm (= 11 in) | 11"×11" gray plate at z = 0 |
| `BASE_PLATE_FRONT_MM` | 67 mm | front edge of plate, +x of turntable axis |
| `FRONT_EXT_WIDTH_MM` | 70 mm | width of front sensor housing (centered LR) |
| `FRONT_EXT_LENGTH_MM` | 142 mm | sensor housing extends to the camera lens |
| `CAMERA_FORWARD_OFFSET_MM` | 209 mm | camera lens = front of robot + 142 |
| `CAMERA_HEIGHT_MM` | −40 mm | camera lens is 40 mm BELOW the base plate |

The sensor housing (lidar + campan + camera) is **flush with the plate top
at z = 0** and extends downward.  Treat the entire footprint as solid below
z = 0 — the arm must stay above z = 0 over the plate AND the sensor housing.

## 3. IK branch selection (IMPORTANT)

A 2-link planar IK has two solutions for any reachable point.  The NUEVO
elbow hinge folds in only one direction, so we always need the same branch:

* **Branch "elbow up"** (our arm): upper arm angled UP from shoulder, forearm
  angled DOWN to the target.  Elbow joint sits ABOVE the straight line from
  shoulder pivot to gripper.
* **Branch "elbow down"** (NOT achievable on our arm): upper arm DOWN, elbow
  below the shoulder→gripper line.  The physical elbow can't fold this way.

`inverse_kinematics()` defaults to `elbow_up=True`.  All test scripts and
programs (turntable_pick_place_test, manual_ik_pick_place_test,
campan_detect_ik_test, manipulator_demo, final_demo, etc.) automatically pick
up this default.  The wrong branch was the cause of "shoulder out of range"
results for legitimate pick targets — the math was solving for the
unachievable elbow direction.

## 4. Joint conventions

### Turntable

```
-90° = robot right (CW limit)
  0° = forward
+90° = robot left
+180° = stow (CCW limit, also home position)
```

Step convention: `firmware_steps = turntable_deg_to_steps(home_offset - target_deg)`.
After firmware homing, stow = step 0 = +180°.  Forward (0°) lives at +3200 steps.

### Shoulder

* `shoulder_geo`:  0° = upper arm horizontal forward; +90° = straight up.
* `shoulder_servo = SHOULDER_SERVO_OFFSET + SHOULDER_SERVO_SIGN × shoulder_geo`
* With our calibration (offset = 96, sign = +1):
  - servo = 90  → geo = −6°  (stow, near horizontal)
  - servo = 135 → geo = +39° (raised, used for ranging)
  - servo = 180 → geo = +84° (close to straight up)

### Elbow

* `elbow_geo`:  180° = fully straight; 0° = forearm folded against upper arm.
* `elbow_servo = ELBOW_SERVO_OFFSET + ELBOW_SERVO_SIGN × (elbow_geo − 180)`
* With our calibration (offset = 90, sign = −1):  `servo = 270 − elbow_geo`
  - servo = 0   → geo = 270° (forearm rotated 90° past straight, elbow-up direction)
  - servo = 90  → geo = 180° (straight)
  - servo = 180 → geo = 90°  (half folded the other way)

## 5. Safe joint limits (advisory)

The flat servo limits from `_manipulator_config.py` are conservative
baselines.  The **real** constraint on the elbow is collision with the
plate + sensor housing, which depends on shoulder angle.

| Limit | Value |
|---|---|
| `SHOULDER_SAFE_MIN/MAX` | 75 / 180 |
| `ELBOW_SAFE_MIN/MAX` | 20 / 160 |
| Physical servo range | 0 to 180 (both) |

### Dynamic safe elbow range (collision-driven)

Measured from `sim_arm_kinematics.py` with sensor housing top at z = 0:

| Shoulder servo | Safe elbow range (servo deg) |
|---|---|
| 75 | [70, 180] |
| 90 | [32, 180] |
| 100 | [16, 180] |
| 105 | [10, 180]  — "ideal" floor ~30 leaves ~20° margin |
| 110 | [4, 180] |
| **120 +** | **[0, 180] — full physical range, any turntable** |
| 135 | [0, 180]  |

Rule of thumb: **at shoulder ≥ 120°, any elbow / any turntable is safe.**
Below 120° you need to keep the elbow high enough that the forearm doesn't
dip into the sensor housing or below the plate edge.

## 6. Ranging pose

Used by the RANGING state in `turntable_pick_place_test.py` to point the
forearm-mounted ultrasonic + the camera at the cup stack.

| Constant | Value |
|---|---|
| `RANGING_SHOULDER_DEG` | 120 (geo +24°, upper arm up) |
| `RANGING_ELBOW_DEG` | 4 (geo 266°, forearm angled ~62° below horizontal) |

Tuned for the **6"+cup-radius (=185 mm) mallow zone** — cup centres on a
semicircle around the camera at 185 mm.  Shoulder 120 is the lower edge of
the "any-elbow-safe" band, so the elbow can swing through its full physical
range without hitting the plate or sensor housing.  Elbow 4 angles the
forearm down enough that the US sensor sits behind the cup centre line at
all bearings — the beam sweeps outward through every cup instead of
overshooting them.  Verified in `sim_arm_kinematics.py`: across the entire
±90° workspace the US returns valid cup distances in the 55–193 mm range
with no hardware collisions.

**Why not the older sh=130 / el=8?**  That pose was tuned for an 11"
(=280 mm) cup zone.  When cups move in to 185 mm, the US sensor sits at
~309 mm radial (further out than the side cups at ~259 mm), so the beam
points *away* from those cups and misses 4 of 7 bearings.  The forearm tip
also brushes through the side cups — collision risk.

### Distance refinement — ultrasonic first, camera fallback

The RANGING state now tries two independent distance estimates and uses
whichever returns a valid reading first.

**1. Ultrasonic (preferred)** — sensor on the forearm, beam along the
forearm direction.  `d_raw` is the 3-D distance from the sensor to the cup's
NEAR wall.  Since the marshmallow sits on the cup's centre axis (not the
wall), we project past the near wall by one cup radius along the horizontal
forearm direction:

```
sensor_horiz = shoulder_offset + L1·cos(sh_geo)
             + ULTRASONIC_FOREARM_OFFSET_MM · cos(forearm_rad)

mallow_reach = sensor_horiz
             + d_raw · cos(forearm_rad)        ← horiz to cup wall
             + CUP_DIAMETER_MM / 2             ← + cup radius to cup centre
```

This back-calculates the radial horizontal distance from the turntable axis
to the cup CENTRE (= mallow xy centre).  Mallow z is the cup-tier height
already snapped during SCANNING.

The geometric assumption is that the beam is aimed at the cup centre, which
holds once the turntable has rotated to the target bearing.

**2. Cup-detection (fallback)** — pinhole formula on the cup bbox:

```
cup_dist = (CUP_DIAMETER_MM × focal_px) / cup_bbox_pixel_width
```

The bbox spans the cup's full outer diameter, so `cup_dist` directly gives
the distance from camera to the cup centre — no offset correction needed.
Used when US is out of range, returns None, or errors.

Both fall back to the SCANNING coarse estimate if neither refinement works.

**Why US first?**  Untested as of this writing — the rationale is that the
ultrasonic gives a direct line-of-sight depth read whereas the camera
formula depends on bbox accuracy and the calibrated focal length.  Verify
on hardware which one tracks ground truth more closely; the order is a
one-line swap in `turntable_pick_place_test.py` if you decide the camera
estimate is more reliable.

Caveat for the US path: the sensor is mounted **above** the forearm
centreline (29 mm) and points along the forearm — it hits the cup wall a
bit higher than centre.  Should be a small effect since the cup is a tall
vertical cylinder, but worth verifying on hardware.

## 7. Marshmallow workspace

Mallow centers live on the **11" semicircle around the camera**.

* Camera centre is at x = 209 mm from the turntable axis.
* Mallow at bearing α from camera: `(209 + 279.4·cos α, 279.4·sin α, z)`
* Heights: 6"–12" above the floor → `z ∈ [−76.6, +75.8]` mm in robot frame.

### Reach reality check

Even within the 11" semicircle, **directly forward (bearing 0°) is out of
arm reach**: the mallow lands at x = 488 mm, distance from shoulder pivot
~521 mm > 471 mm max.  Only bearings ≳ 45° away from straight-forward
are reachable.  Plan placements accordingly, or rotate the robot so the
mallow falls into the reachable arc.

## 8. Place position (constant, validated)

| Constant | Value |
|---|---|
| `PLACE_X_MM` | 128 |
| `PLACE_Y_MM` | −226 |
| `PLACE_Z_MM` | −201  (= 1" above floor) |

IK (elbow_up=True): turntable = −60.5°, shoulder = 98°, elbow = 14°.
The elbow is below the static `ELBOW_SAFE_MIN = 20`, but the collision
check shows the pose is clear because the gripper goes off to the right
side (y = −226 is well outside the plate footprint at ±139.7).  This is a
**known-good special case** — the static safe-range warning is advisory
and can be ignored for this exact pose.

## 9. Demo state machine (turntable_pick_place_test)

```
INIT → IDLE → SAFE_RAISE → ARM_HOME → SCANNING
       → RANGING → APPROACHING → PICKING
       → CARRY_TO_PLACE → PLACING → RESTOW → DONE
```

* **SAFE_RAISE** moves the shoulder UP first, then the elbow — never reverse
  this order or the forearm swings into the chassis.
* **SAFE retract before any turntable rotation**: same shoulder-first rule
  is applied by `_safe_arm_retract` before every `_turntable_to_deg`.
* **APPROACHING** uses the IK result from RANGING directly.  Now that IK
  picks the elbow_up branch by default, these angles match what the
  physical arm can actually execute.

---

## 10. Tools

* **`tools/sim_arm_kinematics.py`** — interactive 3D simulator.  Drag joint
  sliders for FK, target sliders for IK; click preset buttons to snap to
  Place / Plate / Mallow 6"/9"/12".  Shows live collision check, dynamic
  safe-elbow range, and the dynamic IK round-trip.
* **`tools/sim_obstacle_avoidance.py`** — pure-pursuit avoidance tuner.
  Separate scope (drive-time obstacle avoidance), but lives next to the
  arm sim because the workflow is the same: tweak constants in Mac sim,
  copy to test config.

## 11. Key files

| File | Purpose |
|---|---|
| `robot/arm_kinematics.py` | FK / IK (now defaults `elbow_up=True`) |
| `robot/tests/scripts/_manipulator_config.py` | All geometry + servo constants |
| `robot/tests/scripts/turntable_pick_place_test.py` | Competition pick/place demo |
| `robot/tests/scripts/manual_ik_pick_place_test.py` | Hand-pick (x, y, z) IK test |
| `tools/sim_arm_kinematics.py` | Mac simulator (no ROS2 needed) |

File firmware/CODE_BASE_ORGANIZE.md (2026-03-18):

# Code Base Organization Plan

## Goal
- Make the firmware easy to read, reason about, and modify without changing the current working behavior.
- Keep `arduino.ino` as the top-level orchestration file only.
- Separate hard real-time code, fast loop services, periodic soft tasks, and status/debug reporting into clear modules.
- Use this cleanup as the structural step before `v0.9.0`.

## Refactor Principles
- Refactor behavior last. First move code to the right ownership boundaries, then simplify internals.
- Do not move code into a module just because it is currently large. Move it only if the responsibility clearly belongs there.
- Do not create a generic `utility.cpp` dumping ground. Use small purpose-specific modules instead.
- Preserve the current mixed DC control architecture:
  - `TIMER1`: short latch/apply round-robin ISR
  - `loop()`: fast-path polling and staged compute trigger
  - `Scheduler`: millis-based periodic soft tasks only
- Keep debug/status code out of the hot control path as much as possible.

## Important Design Decisions

### 1. `arduino.ino` should be small, but not artificially small
- Target: about `250-350` lines including comments is reasonable.
- The main requirement is not the exact line count; it is that `arduino.ino` reads like an entry point.
- It should answer only these questions:
  - what initializes at boot
  - what ISR vectors exist
  - what soft tasks exist
  - what the main loop order is

### 2. System info code should NOT go into `SystemManager`
- `SystemManager` should stay the firmware state machine and transition owner.
- Status/debug snapshot and printing are a different responsibility.
- Create a dedicated module instead, for example:
  - `src/modules/StatusReporter.h/.cpp`
- That module should own:
  - status snapshot capture
  - chunked debug/status printing
  - formatting of `[SYSTEM]`, `[TIMING]`, `[UART]`
  - windowed counters used only for reporting

### 3. Do not force the fast loop path into the current periodic scheduler
- The current scheduler is millis-based periodic dispatch.
- The current fast loop path is different:
  - `MessageCenter::drainUart()`
  - `MessageCenter::drainTx()`
  - DC compute trigger handling
  - debug chunk emission / flush
- Those need opportunistic servicing every loop iteration, not “run every X ms”.
- So instead of overloading `Scheduler`, create a separate fast-path loop service, for example:
  - `src/runtime/LoopService.h/.cpp`
- Then `loop()` can stay very small while preserving the correct semantics.

### 4. `LoopMonitor` should be integrated at the right level
- Soft periodic tasks can be wrapped by the scheduler.
- ISR timing must remain measured at the ISR call sites.
- So the monitor belongs in two places:
  - inside `Scheduler` for soft tasks
  - explicit calls inside ISR vectors and fast loop services
- Do not try to hide ISR timing inside the scheduler.

## Target Module Boundaries

### `arduino.ino`
Should contain only:
- includes
- global module instances already required by Arduino linkage
- ISR vectors
- `setup()`
- `loop()`
- task callback declarations that are one-line wrappers if Arduino requires them

It should not contain:
- long status formatting code
- large chunks of motor-control coordination logic
- pin/interrupt attachment details
- protocol formatting details

### `src/runtime/AppRuntime.h/.cpp`
Own:
- high-level boot sequence
- registering scheduler tasks
- starting ISR scheduler
- top-level loop service order

Potential public API:
- `AppRuntime::init()`
- `AppRuntime::serviceLoop()`

### `src/runtime/LoopService.h/.cpp`
Own the fast-path operations that must run every loop:
- `MessageCenter::drainUart()`
- `MessageCenter::drainTx()`
- DC compute trigger handling
- status chunk emission
- debug flush timing

Potential public API:
- `LoopService::pollFastPath()`
- `LoopService::pollDeferred()`

### `src/runtime/MotorControlCoordinator.h/.cpp`
Own the mixed ISR/soft coordination state for DC motors:
- round counters
- request/compute/apply bookkeeping
- pipeline counters like `missed/reused/cross`
- helper functions for ISR side and loop side

This is one of the biggest current responsibilities living in `arduino.ino`.

### `src/modules/StatusReporter.h/.cpp`
Own:
- status snapshot struct
- formatting helpers
- windowed reporting counters
- the 1 Hz user-facing report
- immediate event log helpers if needed

This module should consume data from other modules, not own system behavior.

### `src/board/PinMap.h` or improved `pins.h`
Pin constants can stay as a header, but the ownership should be explicit.
- Keep pin numbers and hardware register mapping in one place.
- Do not mix pin definitions with pin attachment logic.

### `src/board/BoardInterrupts.h/.cpp` or fold into existing scheduler modules
Own:
- `attachInterrupt()` calls
- PCINT registration for M3/M4 encoders
- pin-change mask setup
- any board-level interrupt attachment details

The current code base already has `ISRScheduler.*`; that may be the right home if kept focused.

## Concrete Cleanup Tasks

### A. Extract status and debug reporting out of `arduino.ino`
- Move:
  - `StatusSnapshot`
  - formatting helpers
  - chunked `[SYSTEM] / [TIMING] / [UART]` output
  - reporting window resets
- Keep only a single call in the loop path, for example:
  - `StatusReporter::service()`

### B. Extract mixed DC control coordination out of `arduino.ino`
- Move:
  - round counters
  - compute/apply pipeline flags
  - control window counters
  - request/apply bookkeeping
- Keep ISR usage explicit, for example:
  - `MotorControlCoordinator::onTimer1Slot(slot)`
  - `MotorControlCoordinator::serviceSoftCompute()`

### C. Make soft task definitions read as high-level wrappers
- Current task functions are already smaller than before, but they still own some policy.
- Goal:
  - `taskUART()` should call one or two named functions
  - `taskSensors()` should call one named function
  - `taskUserIO()` should not include detailed battery warning policy inline

### D. Clarify hard RT vs fast loop vs periodic soft tasks
- Add a short structure comment near the top of the runtime code:
  - hard RT: ISR vectors only
  - fast loop: every `loop()` iteration
  - periodic soft tasks: scheduler-managed

This matters more than adding many comments to individual lines.

### E. Move board-specific attachment/setup details out of `setup()`
- `setup()` should read like:
  - init board pins
  - init modules
  - register tasks
  - start ISRs
- It should not contain register-level attachment details inline.

### F. Replace the idea of `utility.cpp` with narrow helper modules
- Good:
  - `FormatUtils.cpp`
  - `BoardUtils.cpp`
  - `TimingUtils.cpp`
  - `ControlMath.cpp`
- Bad:
  - one generic `utility.cpp` for unrelated helpers

### G. Clean generated files out of the source tree
- `firmware/arduino/build/` is generated output and should not be treated as source.
- `.DS_Store` should not live in the firmware tree.
- This cleanup belongs in the organization pass too.

## Scheduler and Monitoring Refinement

### Scheduler
- Keep `Scheduler` focused on periodic soft tasks.
- It should know:
  - task interval
  - task callback
  - task priority
  - optional timing/monitor slot

### LoopMonitor
- For periodic soft tasks, measure inside scheduler wrappers.
- For ISR tasks, measure at the ISR site.
- For fast-path loop work, measure in the loop service.
- The monitor output should reflect real ownership boundaries, not arbitrary file boundaries.

## Proposed End-State for `loop()`

The target should look roughly like this:

```cpp
void loop() {
  AppRuntime::serviceLoop();
}
```

And inside `AppRuntime::serviceLoop()`:

```cpp
void AppRuntime::serviceLoop() {
  LoopService::pollFastPath();
  Scheduler::tick();
  LoopService::pollFastPath();
}
```

This keeps the loop readable without forcing the fast path into the periodic scheduler.

## Proposed End-State for `setup()`

The target should look roughly like this:

```cpp
void setup() {
  AppRuntime::init();
}
```

And then `AppRuntime::init()` would call clearly named steps such as:
- `Board::initPins()`
- `Board::attachInterrupts()`
- `Modules::initDrivers()`
- `Modules::initManagers()`
- `AppRuntime::registerTasks()`
- `ISRScheduler::init()`

## Versioning / Scope
- This organization pass should be a structural cleanup only.
- Avoid changing protocol behavior, control timing, or tuning while doing the file moves.
- After the structure is stable and readable, that is the point to advance to `v0.9.0`.

## Suggested Execution Order
1. Extract status reporting into `StatusReporter`.
2. Extract mixed DC round coordination into a dedicated runtime/control module.
3. Extract fast loop path into `LoopService`.
4. Clean up `setup()` and task registration.
5. Move interrupt attachment / board setup out of `arduino.ino`.
6. Integrate soft-task `LoopMonitor` wrapping into `Scheduler`.
7. Remove generated files and stale tree clutter.

## Open Questions
- Do we want `AppRuntime` to be a real module, or do we prefer keeping only a thin `arduino.ino` with free functions?
- Should board-level interrupt attachment live in `ISRScheduler`, or in a separate `BoardInterrupts` module?
- Do we want the status reporter to stay debug-only, or should it also own user-facing summary strings for the UI in the future?

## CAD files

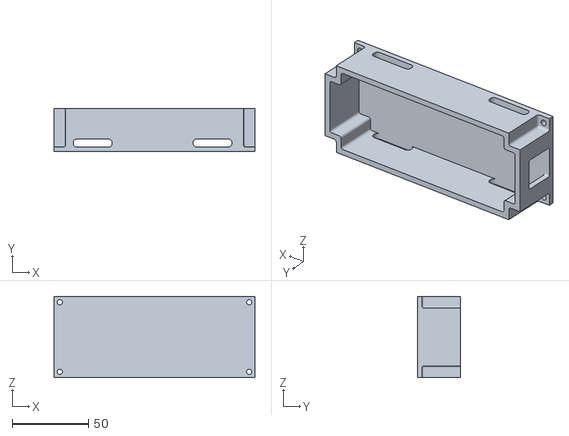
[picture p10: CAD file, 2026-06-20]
mechanical/stl/Chassis/Battery Holder.STL
132.1 x 28.6 x 53.3

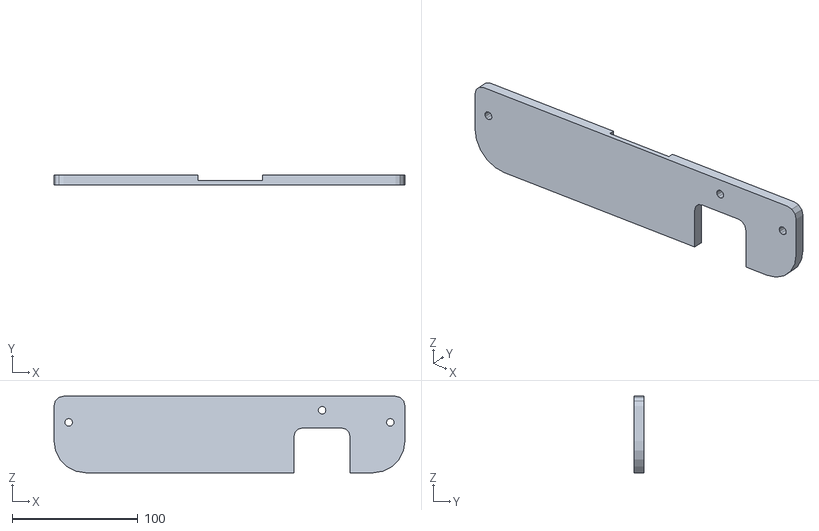
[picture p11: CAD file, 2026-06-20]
mechanical/stl/Chassis/Chassis_Prototype_Plate/Top_Platform_part2_3D_Print.STL
279.4 x 7.62 x 61.0

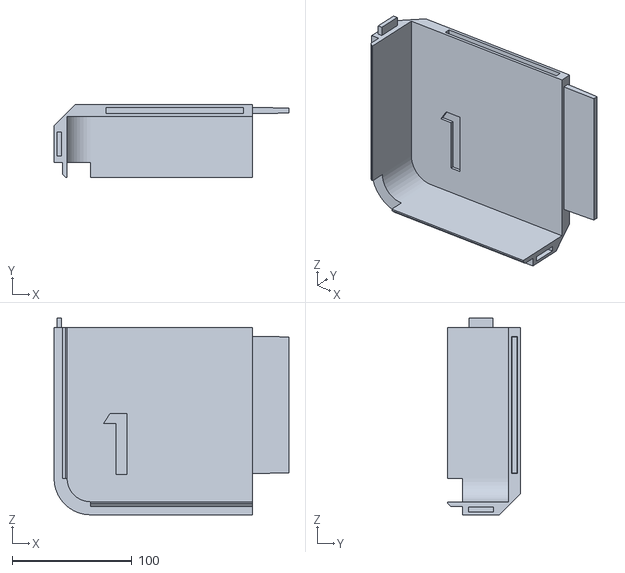
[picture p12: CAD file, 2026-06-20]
mechanical/stl/Enclosure/enclosure_lid_part_1.STL
196.0 x 61.0 x 164.1

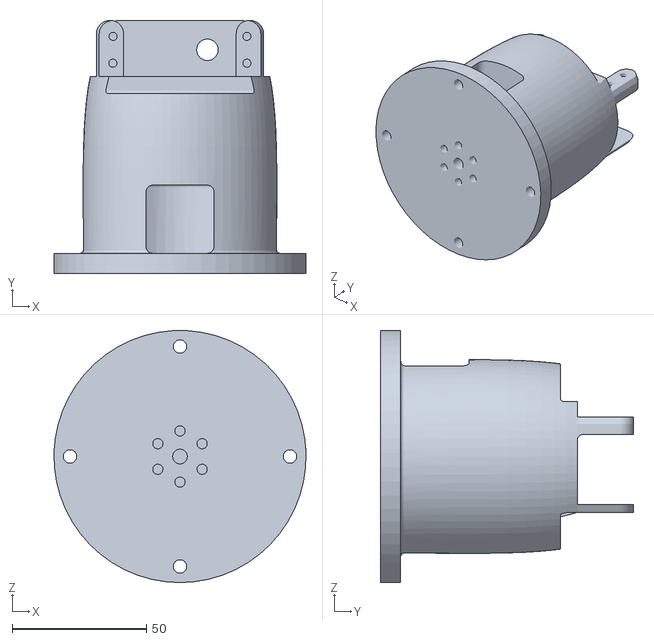
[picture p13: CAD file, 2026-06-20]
mechanical/stl/Manipulator/Turntable/Turntable Adapter Cup.STL
94.0 x 94.5 x 94.0

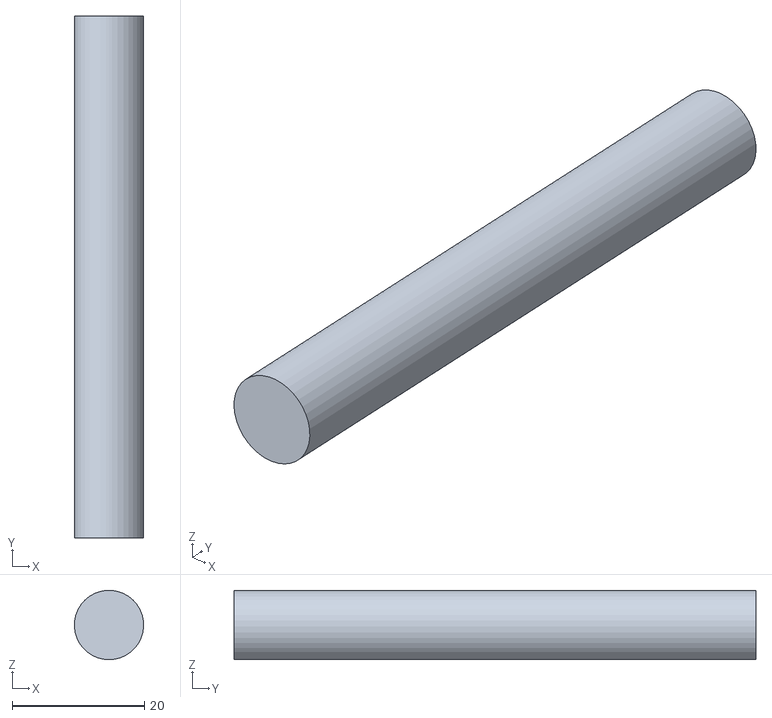
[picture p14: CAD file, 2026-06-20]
mechanical/stl/Suspension/FRONT SUSPENSION/front_middle_suspension_2.STL
10.5 x 79.0 x 10.5

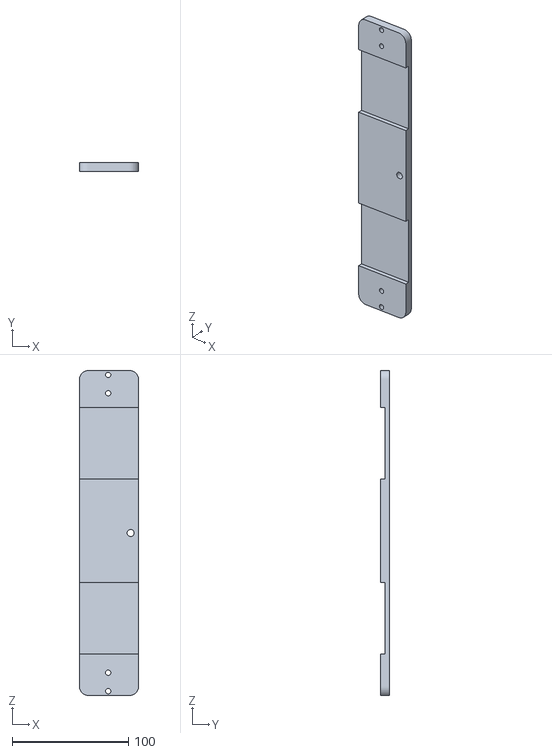
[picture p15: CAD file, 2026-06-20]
mechanical/stl/Chassis/Chassis_Prototype_Plate/Top Platform 3D_Print_part3.STL
50.8 x 7.62 x 279.4

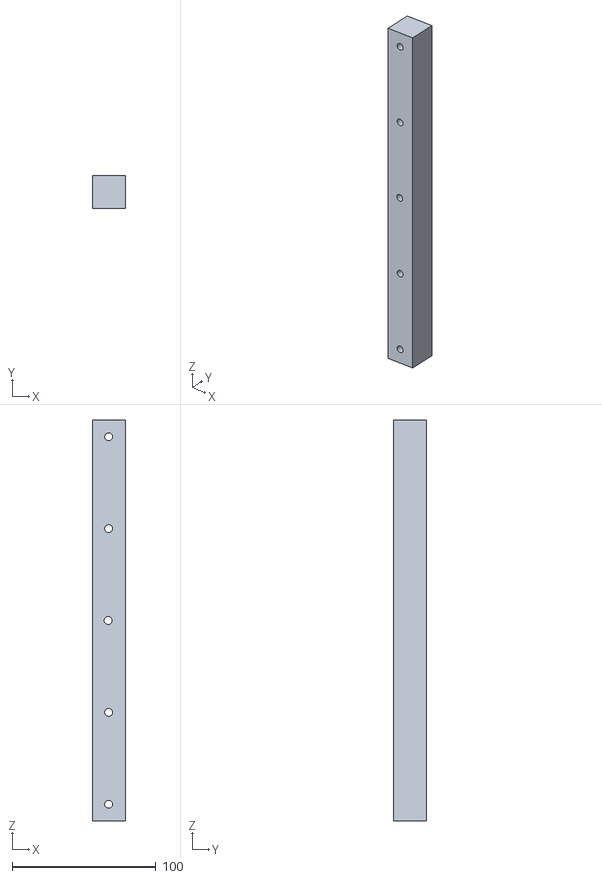
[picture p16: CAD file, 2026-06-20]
mechanical/stl/Chassis/NEW_RISER_Support.STL
22.9 x 22.9 x 279.4

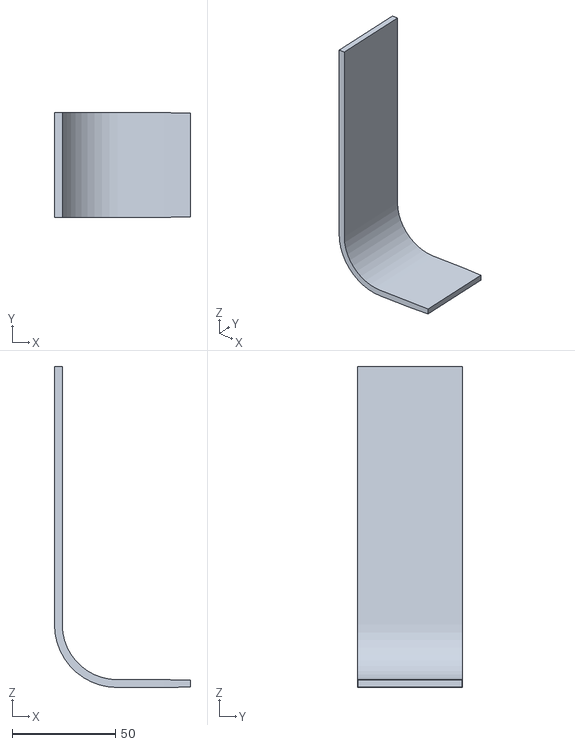
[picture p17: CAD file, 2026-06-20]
mechanical/stl/Enclosure/C Panel.STL
66.0 x 50.8 x 155.7

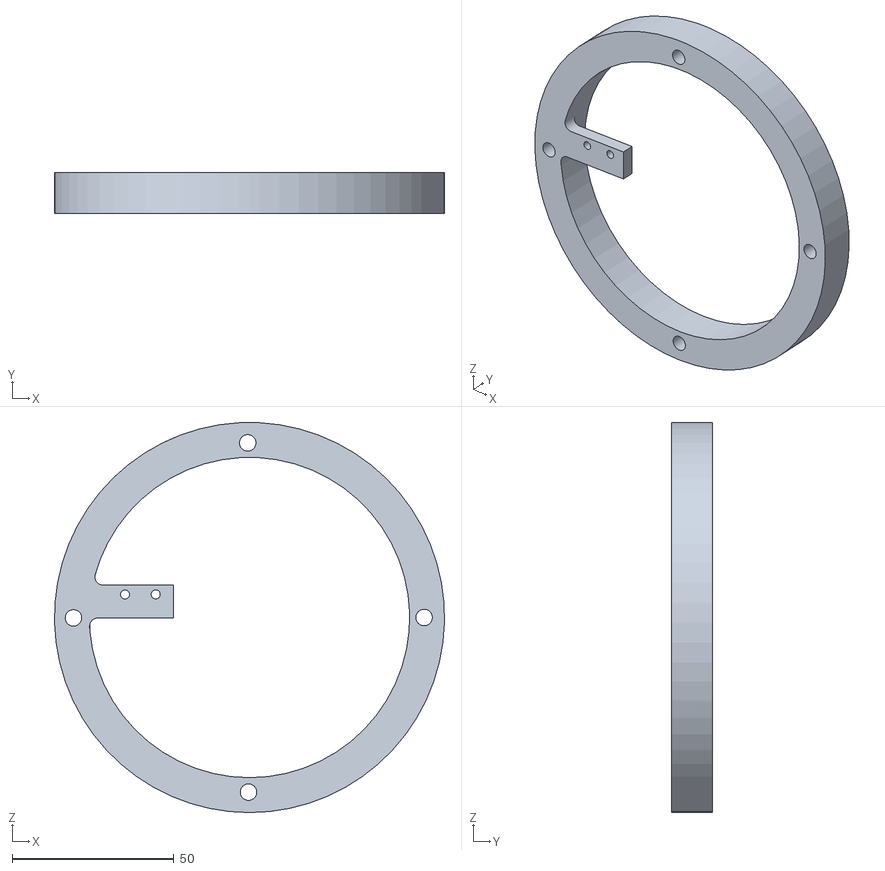
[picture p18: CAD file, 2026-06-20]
mechanical/stl/Manipulator/Turntable/Outer Ring Mount for LS.STL
120.6 x 12.7 x 120.7

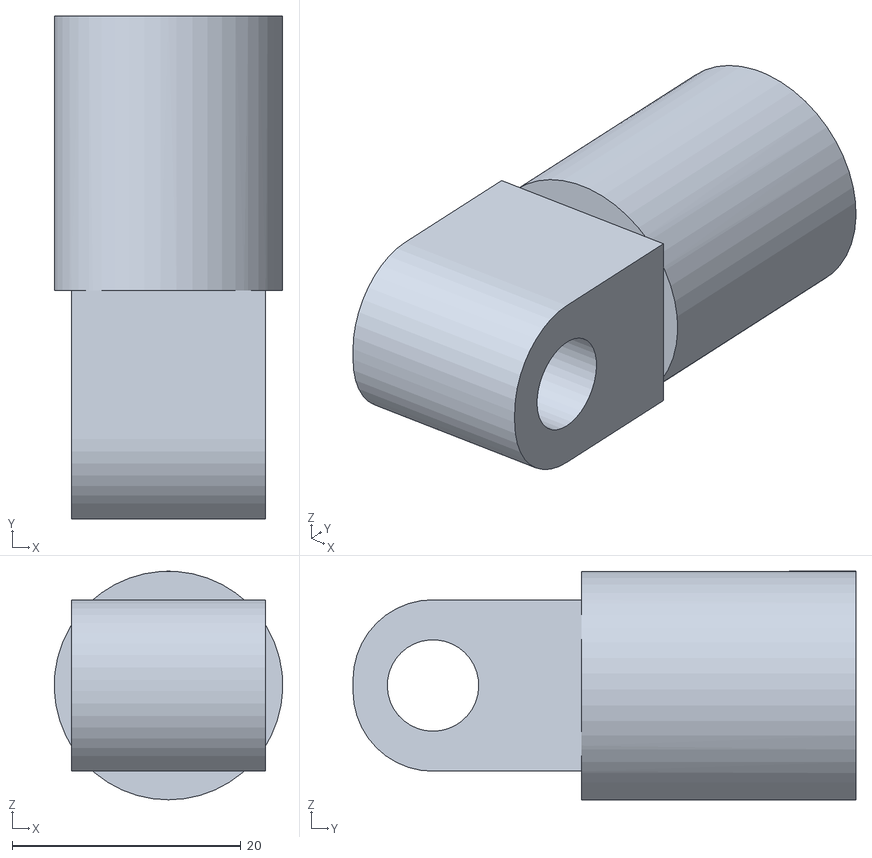
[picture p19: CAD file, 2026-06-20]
mechanical/stl/Suspension/FRONT SUSPENSION/front_bottom_suspension_base.STL
20.0 x 44.0 x 20.0

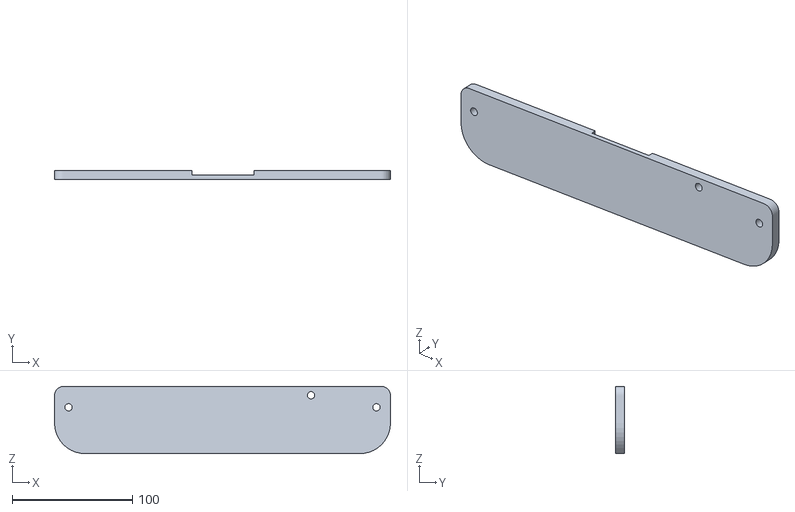
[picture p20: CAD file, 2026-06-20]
mechanical/stl/Chassis/Chassis_Prototype_Plate/Top_Platform_3D_Print_part2.STL
279.4 x 7.62 x 55.9

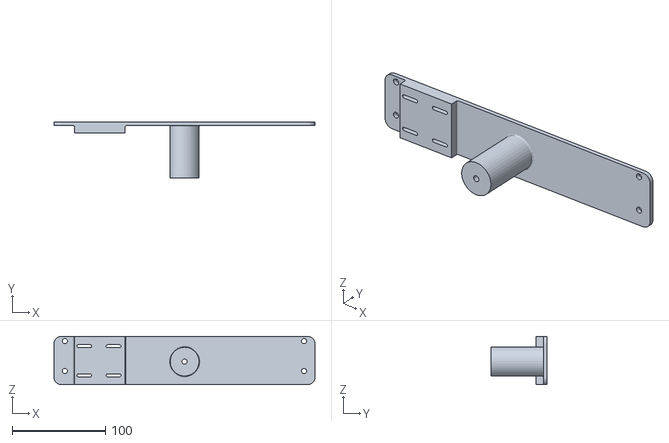
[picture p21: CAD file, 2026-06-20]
mechanical/stl/Chassis/Motor Mount Bridge v3.STL
279.4 x 59.7 x 51.6

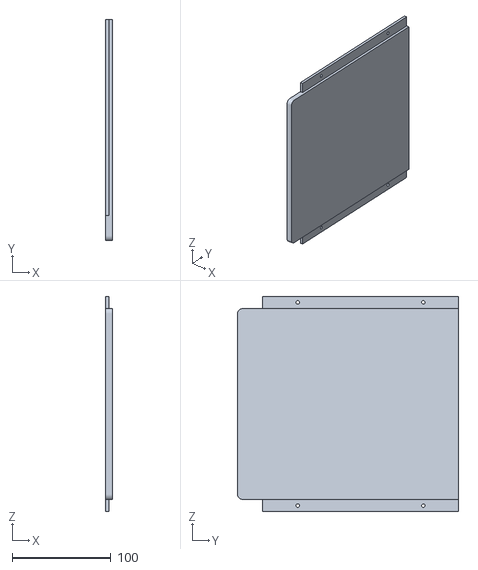
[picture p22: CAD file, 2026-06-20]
mechanical/stl/Enclosure/side_panel.STL
6.60 x 223.5 x 217.4

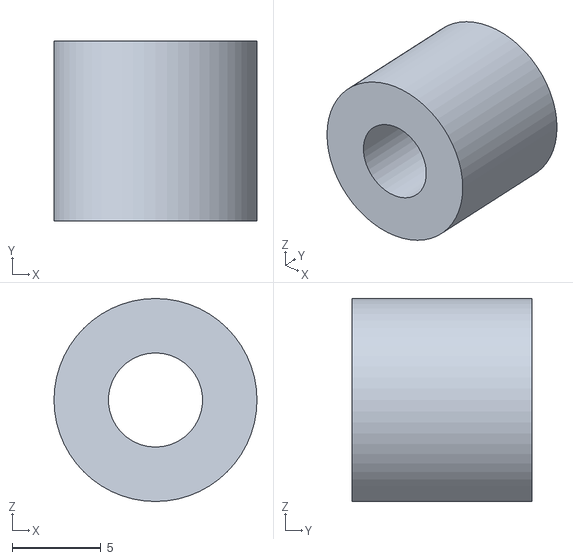
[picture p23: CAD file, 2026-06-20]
mechanical/stl/Manipulator/Turntable/Inner Ring Hard Stop for LS.STL
11.4 x 10.2 x 11.4

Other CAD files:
mechanical/stl/Suspension/FRONT SUSPENSION/pin2_and_3.STL
mechanical/stl/Chassis/Chassis Riser Frame Support v2.STL
mechanical/stl/Chassis/Chassis_Prototype_Plate/Top Platform 3D_Print_part1.STL
mechanical/stl/Enclosure/enclosure_lid_part_3.STL
mechanical/stl/Chassis/Chassis Plate Mid Support.STL
mechanical/stl/Chassis/Electronics_Bridge_Part1.STL
mechanical/stl/Chassis/Electronics_Bridge_Part2.STL
mechanical/stl/Chassis/Motor Mount Bridge.STL
mechanical/stl/Chassis/Motor Mount Bridge_New.STL
mechanical/stl/Enclosure/corner_connections.STL
mechanical/stl/Enclosure/enclosure_lid_part_2.STL
mechanical/stl/Enclosure/enclosure_lid_part_4.STL
mechanical/stl/Enclosure/front_and_back_panel.STL
mechanical/stl/Enclosure/sliding_rails.STL
mechanical/stl/Suspension/FRONT SUSPENSION/cap1_2_and_3.STL
mechanical/stl/Suspension/FRONT SUSPENSION/front_base.STL
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

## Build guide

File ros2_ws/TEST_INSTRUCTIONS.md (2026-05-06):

# Manual Test Instructions

Run these in order. Steps marked **[Mac]** run on your Mac without Docker.
Steps marked **[Docker]** require the container to be running.

---

## 0 — Build frontend and deploy to backend

Do this once before any UI testing, and again after any frontend changes.

```bash
cd nuevo_ui/frontend
npm ci && npm run build
cd ..
cp -r frontend/dist/. backend/static/
```

---

## 1 — Start the container + bridge

```bash
# Start container (builds ROS2 workspace on first run, ~60 s)
docker compose -f ros2_ws/docker/docker-compose.vm.yml up -d --build --wait

# Verify healthy
docker compose -f ros2_ws/docker/docker-compose.vm.yml ps
```

Inside the container, start the bridge (web server + ROS2 node):

```bash
docker compose -f ros2_ws/docker/docker-compose.vm.yml exec ros2_runtime bash -c \
  "source /ros2_ws/install/setup.bash && ros2 launch bridge bridge.launch.py"
```

Open **http://localhost:8000** in your browser and log in.

---

## 2 — ROS2 message types **[Docker]**

```bash
docker compose -f ros2_ws/docker/docker-compose.vm.yml exec ros2_runtime bash -c \
  "source /ros2_ws/install/setup.bash &&
   ros2 interface show bridge_interfaces/msg/FusedPose &&
   ros2 interface show bridge_interfaces/msg/LidarWorldPoints"
```

**Expected:**
```
std_msgs/Header header
float32 x
float32 y
float32 theta
bool gps_active
---
std_msgs/Header header
float32[] xs
float32[] ys
float32 robot_x
float32 robot_y
float32 robot_theta
```

---

## 3 — APF planner unit tests **[Mac]**

```bash
cd ros2_ws/src/robot
python3 -m pytest test/test_path_planner.py -v
```

**Expected:** 6 passed.

---

## 4 — Lidar scan math **[Mac]**

```bash
cd ros2_ws/src/robot
python3 - <<'EOF'
import sys, numpy as np
sys.path.insert(0, '.')
from robot.lidar_scan import LidarConfig, LidarScan

class FakeScan:
    def __init__(self, a, r):
        self.angle_min = a[0]; self.angle_max = a[-1]; self.ranges = r

cfg = LidarConfig(yaw_deg=0.0)
sc = LidarScan(cfg)
pts = sc.process(FakeScan([0.0, 0.1], [1.0, 13.0]))
assert pts.shape == (1, 2) and abs(pts[0,0] - 1000) < 0.5, pts
print("PASS: forward ray 1 m →", pts[0])

pts2 = sc.to_world_frame(np.array([[500., 0.]]), (100., 0., 0.))
assert abs(pts2[0,0] - 600) < 0.1, pts2
print("PASS: world frame shift →", pts2[0])
EOF
```

**Expected:** 2 PASS lines.

---

## 5 — ROS Nodes card **[Docker + browser]**

With the bridge running, open **http://localhost:8000** → scroll to **RPi Sensors**.

- [ ] "ROS Nodes" card is visible
- [ ] Click to expand — shows a list of nodes
- [ ] Click a node → shows Publishes / Subscribes lists
- [ ] Refreshes automatically every ~0.7 s

---

## 6 — World canvas and GPS card — fake data **[Docker + browser]**

Run in a second terminal while the bridge is running:

```bash
docker compose -f ros2_ws/docker/docker-compose.vm.yml exec ros2_runtime bash -c \
  "source /ros2_ws/install/setup.bash
   for i in \$(seq 0 30); do
     ros2 topic pub --once /fused_pose bridge_interfaces/msg/FusedPose \
       \"{x: \$((i * 40)).0, y: \$((i * 15)).0, theta: 0.05, gps_active: false}\"
     sleep 0.15
   done"
```

In the browser (**RPi Sensors** section):

- [ ] World canvas appears with a robot dot moving along a trail
- [ ] Fused trail (green) accumulates
- [ ] GPS card shows **NO** in red (gps_active: false)
- [ ] Toggle buttons (Odometry / GPS / Fused / Lidar) show/hide trails

Now publish one pose with `gps_active: true`:

```bash
docker compose -f ros2_ws/docker/docker-compose.vm.yml exec ros2_runtime bash -c \
  "source /ros2_ws/install/setup.bash &&
   ros2 topic pub --once /fused_pose bridge_interfaces/msg/FusedPose \
     '{x: 500.0, y: 300.0, theta: 0.5, gps_active: true}'"
```

- [ ] GPS card switches to **YES** in green

---

## 7 — Bridge WebSocket relay **[Docker + browser console]**

```js
// Paste in browser dev console:
const ws = new WebSocket('ws://localhost:8000/ws?token=<your_token>');
ws.onmessage = (e) => {
  const m = JSON.parse(e.data);
  if (['fused_pose','gps_status','lidar_world_points','ros_nodes'].includes(m.topic))
    console.log(m.topic, m.data);
};
```

**Expected within 5 s:**
- `ros_nodes` message appears with node list
- `fused_pose` appears when publishing the fake topic above
- `gps_status.is_detected` → `false` normally, `true` when fused_pose has gps_active: true

---

## 8 — RPi with hardware (robot required)

These steps need an RPi with Arduino + RPLidar connected.

### 8a — Robot drives to goal
```bash
# On RPi inside container:
ros2 run robot new_example
```
- Robot moves toward GOAL_MM (default 1000, 0 mm)
- Lidar dots appear in the World Canvas
- Robot deflects around obstacles
- Logs "Reached goal" when within 60 mm

### 8b — GPS card (camera required)
- With ArUco tag in camera view: GPS card shows **YES** in green with X, Y coordinates
- Tag disappears → card reverts to **NO** within 1 s

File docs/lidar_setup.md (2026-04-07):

# Outside Docker
1. Pull the latest repo
Inside your project root directory (Project-NUEVO)
```git pull```

2. Stop any running Docker containers
```docker compose -f $COMPOSE down```

3. Rebuild the container (one-time)
```docker compose -f $COMPOSE build```

4. Restart Docker and enter docker terminal
```bash
docker compose -f $COMPOSE up -d
docker compose -f $COMPOSE logs -f ros2_runtime
docker compose -f $COMPOSE exec ros2_runtime bash
```

5. Check if the lidar device is present
```sudo chmod 777 /dev/ttyUSB0```

# Inside Docker
1. Source ROS2 environment
```bash
source /opt/ros/jazzy/setup.bash
source /ros2_ws/install/setup.bash
```

2. Start ROS2 node of the Lidar
```bash
ros2 run rplidar_ros rplidar_node --ros-args   -p channel_type:="serial"   -p serial_port:="/dev/rplidar"   -p serial_baudrate:=460800   -p frame_id:="laser_frame"   -p angle_compensate:=true   -p scan_mode:="Standard"
```

# Open Docker in the Second terminal
1. Source ROS2 environment
```bash
source /opt/ros/jazzy/setup.bash
source /ros2_ws/install/setup.bash
```

2. Start ROS2 sensor node
```ros2 run sensors sensor_node```

# In the Third terminal
1. Copy the lidar result Inside your project root directory (Project-NUEVO)
```docker cp docker-ros2_runtime-1:/data/plot.png .```

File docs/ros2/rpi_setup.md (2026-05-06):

# Raspberry Pi Setup

## Enable UART on a Pi 5
Edit config.txt
```bash
sudo nano /boot/firmware/config.txt
```

Find the uart enable option and edit:
```bash
enable_uart=1
dtoverlay=uart0-pi5
```

Also disable serial console:
```bash
sudo nano /boot/firmware/cmdline.txt
```

Remove anything like:
```bash
console=serial0,115200
console=ttyAMA0,115200
```
Save the file and reboot.

## Verify
```
ls -l /dev/ttyAMA0
```

You should see something like:
```bash
crw-rw---- 1 root dialout 204, 64 Mar 10 14:02 /dev/ttyAMA0
```

The current bridge runtime uses:

```text
/dev/ttyAMA0 @ 200000 baud
```

## Enable the Pi Camera Service

The Pi CSI camera runs on native Ubuntu 25.10 and is exposed to Docker through a
v4l2loopback device. Run this once from the repository root on the Raspberry Pi
host:

```bash
./ros2_ws/host_camera/install.sh
```

The installer sets up:

```text
/dev/video10
```

as the Project NUEVO virtual camera, installs the native Ubuntu camera packages
(`libcamera-tools`, `rpicam-apps-lite` or `rpicam-apps`, v4l2loopback, and
ffmpeg), and enables `nuevo-pi-camera-feed.service` so the feed starts
automatically at boot and restarts after failures.

If the installer changed boot camera config, reboot the Pi before validating
the camera path.

After the ROS2 image is built/running, verify both host and Docker access:

```bash
./ros2_ws/docker/enter_ros2.sh --build rpi
exit
./ros2_ws/host_camera/check.sh
```

Expected test images:

```text
/tmp/nuevo_camera_check/host_loopback.jpg
/tmp/nuevo_camera_check/docker_loopback.jpg
```

Useful service commands:

```bash
sudo systemctl status pi-camera-feed.service
sudo systemctl restart pi-camera-feed.service
sudo journalctl -u pi-camera-feed.service -f
```

### Camera compatibility note

Default camera policy:

```text
camera_auto_detect=1
display_auto_detect=1
```

That keeps most camera modules working without a hardcoded overlay.

Known exception in the current lab setup:
- **Arducam 12MP IMX708 Camera Module 3** on Pi 5 may fail with auto-detect
- validated fallback:

```text
camera_auto_detect=0
dtoverlay=imx708,cam0
display_auto_detect=1
```

This fallback is module-specific. Do not make it the global default unless that
camera is the standard lab hardware.

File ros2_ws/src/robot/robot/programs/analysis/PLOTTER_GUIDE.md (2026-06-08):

# Navigation Plotter — Usage Guide

Two scripts work together to capture and visualize a driving run:

| Script | Runs on | Purpose |
|---|---|---|
| `nav_data_recorder.py` | Pi (inside Docker) | Records live ROS data to a JSON file |
| `plot_nav_results.py` | Mac (no ROS needed) | Reads the JSON and generates PNG figures |

---

## Step 1 — Record a run on the Pi

Open a **5th terminal** (alongside your normal 4-terminal startup). Start the recorder **before** launching the robot node, then do your run normally.

```bash
# Enter the container
docker compose -f ros2_ws/docker/docker-compose.rpi.yml exec ros2_runtime bash

# Source ROS2
source /opt/ros/jazzy/setup.bash && source /ros2_ws/install/setup.bash

# Start recording (default output: /runtime_output/nav_run_YYYYMMDD_HHMMSS.json)
python3 /ros2_ws/src/robot/robot/tests/scripts/nav_data_recorder.py
```

To specify a custom output path:
```bash
python3 nav_data_recorder.py --out /runtime_output/my_run.json
```

**Stop recording:** press `Ctrl+C`. The JSON file is written at that point.

What gets recorded:

| Data | Source topic | Rate |
|---|---|---|
| Odometry (x, y, θ) | `/sensor_kinematics` | 5 Hz |
| GPS-fused pose (x, y, θ, gps_active) | `/fused_pose` | 5 Hz |
| Lidar point cloud (world frame) | `/scan` | 1 Hz (one snapshot/s) |
| Vision detections (class, confidence, attributes) | `/vision/detections` | every event |

The recorder is **read-only** — it never commands the robot. Run it alongside any driving script without interference.

---

## Step 2 — Copy the JSON to your Mac

```bash
scp mae162-s4-g7@192.168.8.152:/runtime_output/nav_run_*.json ./
```

Or a specific file:
```bash
scp mae162-s4-g7@192.168.8.152:/runtime_output/nav_run_20260603_142000.json ./
```

---

## Step 3 — Install dependencies (first time only)

```bash
pip install matplotlib numpy
```

---

## Step 4 — Generate figures

All commands run from the `tests/scripts/` directory (or use full paths).

### FSM state machine diagram (no run data needed)

```bash
python3 plot_nav_results.py --fsm
```

Generates `fig_fsm_diagram.png` — a diagram of the full-course FSM with all states, sub-phases, transitions, and start modes. This is already pre-generated at the repo root as `fig_fsm_diagram.png`.

### All figures from a recorded run

```bash
python3 plot_nav_results.py nav_run_20260603_142000.json
```

### All figures including the FSM diagram

```bash
python3 plot_nav_results.py nav_run_20260603_142000.json --fsm
```

### Write figures to a specific folder

```bash
python3 plot_nav_results.py nav_run_20260603_142000.json --fsm --out-dir ./slides/
```

---

## Output figures

| File | Contents | Needs run data? |
|---|---|---|
| `fig_fsm_diagram.png` | State machine: IDLE → SEG1 → SEG2 → SEG3 (3A/3B/3C) → SEG4 → DONE | No |
| `fig_trajectory_map.png` | Venue grid + planned path (yellow) + odometry (blue) + GPS-fused (green dashed) + lidar obstacle cloud (red) + checkpoints | Yes |
| `fig_heading_fusion.png` | Heading over time (odom vs fused) + GPS correction magnitude with shaded GPS-active windows | Yes |
| `fig_vision_timeline.png` | Detection confidence scatter over time, color-coded by class (green/red traffic light, stop sign, etc.) | Yes |

All figures use the dark NUEVO color scheme and save at 180 dpi.

---

## Tips

- **Run the recorder before starting the robot node** so it catches the very first odometry reset and all detections from the start.
- If the vision node is not running with `debug_save_enabled:=true`, vision detections still appear in the JSON (the recorder reads `/vision/detections` directly — independent of the debug image saver).
- The lidar snapshots are projected to world frame using the latest fused pose. If GPS is not active, the projection uses odometry, which drifts in the obstacle zone — that's expected and actually visible in the trajectory figure.
- For the cleanest trajectory figure, run `START_SEGMENT = 1` (full course from start) so the origin is at (0, 0) matching the plotter's course geometry.
- The JSON files can be large (a full run is ~1–3 MB). Copy them off the Pi promptly since `/runtime_output` is on a tmpfs and does not survive a reboot.

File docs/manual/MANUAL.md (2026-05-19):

# NUEVO Board and Firmware Manual

**NUEVO** = **N**avigation **U**nit for **E**ducation and **V**ersatile **O**perations
**Board Revision:** Rev. B · **Firmware:** v0.9.8

---

## Table of Contents

1. [System Architecture Overview](#1-system-architecture-overview)
2. [Getting Started](#2-getting-started)
3. [NUEVO Board Hardware](#3-nuevo-board-hardware)
4. [NUEVO UI](#4-nuevo-ui)
5. [Firmware](#5-firmware)
6. [Software — ROS2 Nodes](#6-software--ros2-nodes)
7. [Sensors and I2C Devices](#7-sensors-and-i2c-devices)
8. [Communication Protocol](#8-communication-protocol)
9. [Safety and Fault Handling](#9-safety-and-fault-handling)
10. [Troubleshooting](#10-troubleshooting)
11. [Appendix A: config.h Quick Reference](#appendix-a-configh-quick-reference)
12. [Appendix B: Pin Table (Rev. B)](#appendix-b-pin-table-rev-b)

---

## 1. System Architecture Overview

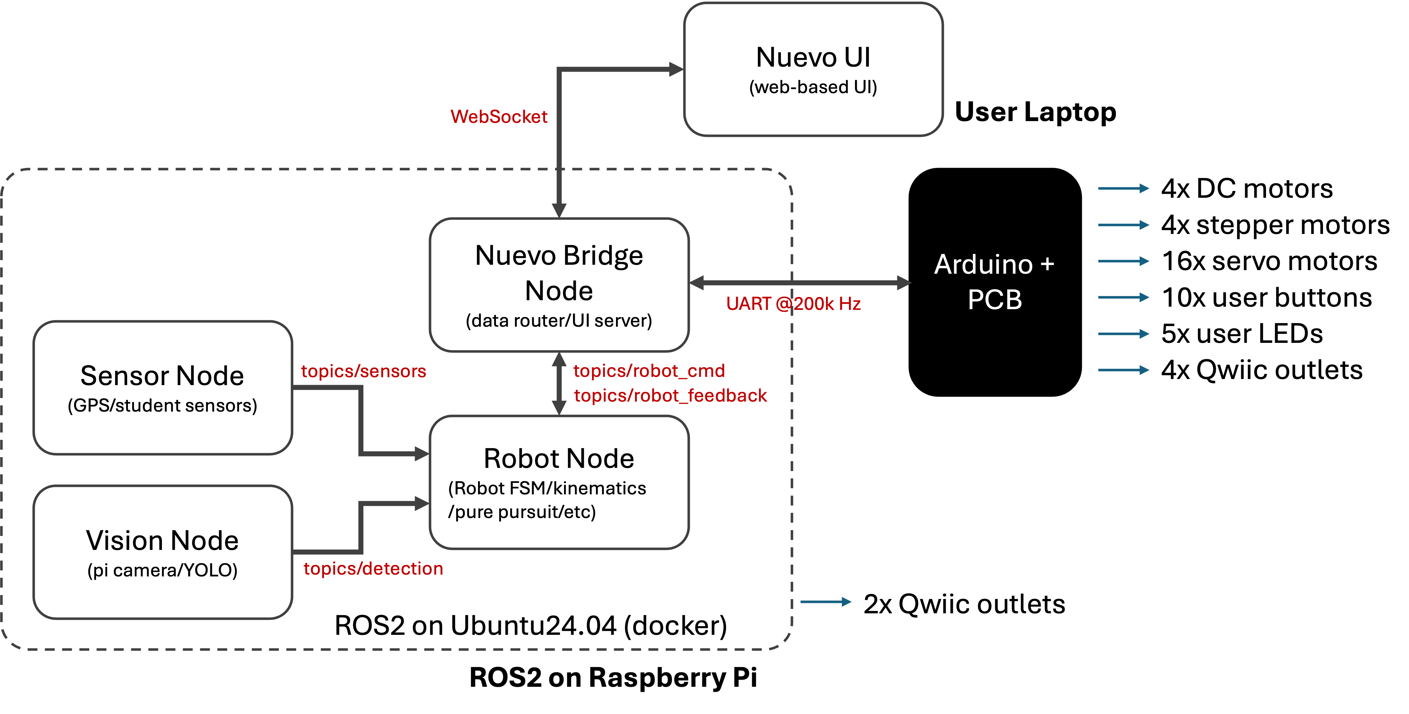
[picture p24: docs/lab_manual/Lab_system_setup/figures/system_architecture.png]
System Architecture Diagram


The NUEVO platform has four major components that work together:

- **NUEVO Board** — the custom PCB that integrates power management, motor drivers, and signal routing for all actuators and sensors
- **Firmware** — C++ code running on the Arduino Mega 2560 that handles real-time motor control, encoder counting, IMU, and low-level safety
- **NUEVO Bridge / UI** — a Python backend (`nuevo_bridge`) and React web frontend that provide teleoperation, monitoring, and configuration
- **ROS2 Nodes** — a ROS2 workspace on the Raspberry Pi 5 that wraps the same bridge runtime for use in ROS-based systems

The Arduino and the Raspberry Pi communicate through a UART serial link using a compact TLV (Type-Length-Value) protocol at 200 kbps. The Raspberry Pi is the high-level controller for decision-making and path planning; the Arduino is the low-level controller for real-time actuation and safety enforcement.

```
  [ Browser / ROS2 client ]
          |
    WebSocket / ROS topics
          |
  [ nuevo_bridge (FastAPI, Python) ]  ← runs on Raspberry Pi 5
          |
    UART Serial @ 200 kbps (TLV protocol)
          |
  [ Arduino Mega 2560 firmware ]  ← runs on NUEVO Board
          |
  [ Motors · Encoders · Steppers · Servos · IMU · LEDs · Buttons ]
```

---

## 2. Getting Started

### 2.1 Before You Power Up

- [ ] Visually inspect the PCB for damage, solder bridges, or loose components
- [ ] Verify all plug-in modules are properly seated: both H-bridge modules, all stepper driver modules, and the PCA9685 servo controller
- [ ] Check that the 15A blade fuse is installed
- [ ] Ensure the main power switch is in the OFF position
- [ ] If using servos, confirm the servo rail voltage is appropriate for your servos (see [Section 3.6](#36-servo-motors))

### 2.2 Power Sources

The board supports two mutually compatible power inputs:

| Source | Connector | Voltage Range | Notes |
|---|---|---|---|
| Battery | XT60 female (J_BAT) | 7.4 V – 24 V | Powers all motors; 12V NiMH (10-cell) is default |
| Raspberry Pi USB-C | RPi port | 5V via RPi | Powers Arduino and RPi only; motors not powered |

An ideal-diode circuit prevents backflow between the two sources, so they can be connected simultaneously. Use the USB-C path during software development when the battery is not needed.

> **H-bridge voltage limit:** The default H-bridge modules support a **maximum of 12V**. If using a battery above 12V (4S LiPo or higher), replace the H-bridge modules with higher-voltage rated alternatives (e.g. BTS7960 for up to 27V) before connecting.

### 2.3 First Power-Up

1. Connect the battery or plug in the RPi USB-C cable
2. Flip the main power switch ON
3. Verify LEDs:
   - **5V rail LED** (green) — should illuminate; confirms the buck converter is active
   - **Servo rail LED** (green) — should illuminate if the servo rail jumper is closed
   - **Power-good LED** — illuminates when 5V is provided by the on-board buck converter (not when backfed from USB-C)
4. Upload firmware to the Arduino via USB-B (see [Section 5.2](#52-build-and-upload))
5. Once firmware is running, the NeoPixel RGB LED on pin 42 will show system state — it should show the IDLE color shortly after boot
6. Connect the Raspberry Pi and start the bridge to begin communicating (see [Section 4.2](#42-starting-the-bridge))

### 2.4 Accessing the Web UI

Once the bridge is running on the Raspberry Pi, the NUEVO UI is accessible from any browser on the same network:

```
http://<raspberry-pi-ip>:8000
```

If running on the development machine with the Docker VM compose file (no hardware), the UI is at:

```
http://localhost:8000
```

---

## 3. NUEVO Board Hardware

### 3.1 Power Rails

The board provides three regulated output rails derived from the battery input:

| Rail | Voltage | Max Current | Consumers |
|---|---|---|---|
| 5V_SYS | 5.0V (regulated) | 6A | Raspberry Pi 5, Arduino, encoders, logic |
| 3V3_SYS | 3.3V (LDO from 5V) | 1A | Qwiic devices on Arduino bus |
| SERVO_VOUT | 5–10V (adjustable) | 6A | PCA9685 and all servo motors |

Power path from battery:
1. XT60 connector → P-channel MOSFET (reverse-polarity protection)
2. → 15A replaceable blade fuse
3. → TVS2700DRVR surge clamp (27V flat)
4. → Dual DC-DC buck converters (5V_SYS and SERVO_VOUT)
5. → AMS1117-3.3 LDO (3V3_SYS from 5V_SYS)

The 5V_SYS rail can also be backfed from the Raspberry Pi's USB-C port through an ideal-diode circuit, allowing the Arduino to run without a battery connected.

Upper screw terminal power outputs (for external connections):

| Label | Available outputs | Voltage |
|---|---|---|
| GND | 8 terminals | Ground |
| BAT | 4 terminals | Battery voltage (7.4–24V) |
| 3V3_SYS | 4 terminals | 3.3V (1A shared) |
| 5V_SYS | 4 terminals | 5V (6A shared) |
| SERVO_VOUT | 4 terminals | Adjustable 5–10V (6A shared) |

### 3.2 Raspberry Pi 5

- Installed at the bottom-left corner of the board
- Powered from 5V_SYS (battery or USB-C)
- Communicates with the Arduino through UART Serial2 via a 5V ↔ 3.3V level shifter
  - Arduino TX2 (pin 16) → RPi GPIO15 (RXD)
  - Arduino RX2 (pin 17) ← RPi GPIO14 (TXD)
  - Default baud rate: **200,000 bps**
- The RPi's own I2C1 bus (GPIO2/GPIO3) connects to two dedicated Qwiic headers — these are separate from the Arduino's I2C bus
- The 40-pin GPIO header is otherwise available for general use

### 3.3 Arduino Mega 2560

The Arduino is the low-level real-time controller. It handles:
- DC motor PWM, direction, and encoder feedback
- Stepper motor step/direction/enable pulses
- Servo motor commands via PCA9685 over I2C
- IMU and voltage monitoring
- User buttons, limit switches, and LED outputs
- TLV communication with the Raspberry Pi over Serial2

It is programmed via the USB-B port on the board. See [Section 5](#5-firmware) for firmware installation.

> **Serial port reservations:** Serial1 (pins 18/19) is used for M2 encoder interrupts and is not available. Serial3 (pins 14/15) is used for stepper STEP signals and is not available.

### 3.4 DC Motors

The board supports up to four DC motors with quadrature encoder feedback, driven by two dual-channel H-bridge modules.

- **Channels M1 and M2** — encoder phases on dedicated hardware interrupt pins (INT0/INT1 for M1, INT4/INT5 for M2), enabling full 4× quadrature decoding at up to ~9600 edges/second at 100 RPM
- **Channels M3 and M4** — encoder phases on Pin Change Interrupt (PCINT) pins; also full 4× mode
- Encoder resolution: 1440 PPR (manufacturer spec), which gives 1440 counts/revolution in 4× mode
- Current sensing is available on all four channels (analog pins A3–A6), disabled by default

Each encoder connects to the board through a 4-pin keyed connector (VCC, GND, A, B). See [firmware/docs/encoder_ISR.md](../../firmware/docs/encoder_ISR.md) for full details on the interrupt and counting implementation.

Motor control in the firmware uses a cascaded PID loop. See [firmware/docs/motion_control.md](../../firmware/docs/motion_control.md) for details.

### 3.5 Stepper Motors

The board has four on-board sockets for A4988 or DRV8825 stepper driver modules.

- Each driver has a blue LED indicator: **LED on = driver enabled**
- Enable each driver by inserting the EN jumper header under the driver socket; the firmware will also enable/disable the driver programmatically
- Microstepping is configured via three jumpers per driver (MS1, MS2, MS3):

| MS1 | MS2 | MS3 | A4988 Mode | DRV8825 Mode |
|-----|-----|-----|---|---|
| Open | Open | Open | Full step | Full step |
| Closed | Open | Open | 1/2 | 1/2 |
| Open | Closed | Open | 1/4 | 1/4 |
| Closed | Closed | Open | 1/8 | 1/8 |
| Closed | Closed | Closed | 1/16 | 1/32 |

> **Maximum step rate:** The firmware stepper timer runs at 10 kHz, giving a maximum of 5000 steps/second per motor. Factor in your microstepping setting when calculating maximum RPM.

#### Current Limit Setting

Each A4988 and DRV8825 module has a small trimmer potentiometer on the top surface used to set the maximum coil current. Setting this correctly is important: too low and the motor loses torque or stalls; too high and the driver or motor overheats.

The current limit is set by measuring the **VREF voltage** at the potentiometer wiper (or the dedicated test point on the module) relative to GND with a multimeter, then adjusting until the target voltage is reached.

**A4988** — current limit formula:

$$I_{max} = \frac{V_{REF}}{8 \times R_{CS}}$$

where $R_{CS}$ is the current-sense resistor value on the module (typically **0.050 Ω** on most breakout boards, sometimes 0.068 Ω or 0.100 Ω — check your board's silkscreen or datasheet).

| $R_{CS}$ | $V_{REF}$ for 1.0 A | $V_{REF}$ for 1.5 A | $V_{REF}$ for 2.0 A |
|---|---|---|---|
| 0.050 Ω | 0.40 V | 0.60 V | 0.80 V |

**DRV8825** — current limit formula:

$$I_{max} = \frac{V_{REF}}{5 \times R_{CS}}$$

where $R_{CS}$ is typically **0.100 Ω** on Pololu-style DRV8825 modules (SMD resistors labeled "R100").

| $R_{CS}$ | $V_{REF}$ for 1.0 A | $V_{REF}$ for 1.5 A | $V_{REF}$ for 2.0 A |
|---|---|---|---|
| 0.100 Ω | 0.50 V | 0.75 V | 1.00 V |

**Procedure:**

1. Power the board (the motor does not need to be moving)
2. Place the multimeter negative probe on GND
3. Touch the positive probe to the VREF test point on the driver module (the center of the trimmer pot on A4988; the dedicated via/pad on DRV8825)
4. Turn the trimmer slowly clockwise to increase VREF (increases current), counterclockwise to decrease
5. Set VREF to the value corresponding to your target current from the tables above
6. Do not exceed the stepper motor's rated current — check the motor datasheet

> **Note:** When using microstepping, the A4988 automatically reduces current on idle phases. The DRV8825 does not — consider setting the current limit to ~70% of rated current if the driver runs hot in microstepping mode.

> **Thermal caution:** Always attach the heatsink to the driver IC before running motors. Both the A4988 and DRV8825 will thermal-shutdown around 150°C without a heatsink at moderate currents.

### 3.6 Servo Motors

Servos are driven by the PCA9685 I2C PWM controller, which supports up to 16 channels.

- The PCA9685 connects to the Arduino's I2C bus (pins 20/21, shared with the IMU)
- Servo power (SERVO_VOUT) is connected to the PCA9685 VCC rail via the `JP_SERVO_PWR` jumper (closed by default)
- Adjust the servo rail voltage with the `POT_SERVO` trimmer potentiometer:
  - Clockwise increases voltage; counterclockwise decreases
  - Typical settings: 5–6V for standard analog servos, 6–7.4V for high-torque servos
  - Measure at the servo rail test point with a multimeter before connecting servos
- Servos plug into the PCA9685 module directly, not into the main PCB

> **Voltage warning:** Most standard servos are rated for 4.8–6V. Do not exceed the servo's rated voltage.

### 3.7 Limit Switches and User Buttons

The board has 10 user button inputs and 8 limit switch inputs. Buttons 3–10 and limit switches 1–8 share the same Arduino input pins — each dual-purpose connector has both an on-board tactile button and a 3-pin JST XH connector for an external switch.

| Button | Limit Switch | Arduino Pin | Notes |
|---|---|---|---|
| BTN1 | — | 38 | Dedicated on-board button only |
| BTN2 | — | 39 | Dedicated on-board button only |
| BTN3 | LIM1 | 40 | Dual-purpose: button + external connector |
| BTN4 | LIM2 | 41 | Dual-purpose: button + external connector |
| BTN5 | LIM3 | 48 | Dual-purpose: button + external connector |
| BTN6 | LIM4 | 49 | Dual-purpose: button + external connector |
| BTN7 | LIM5 | 50 | Dual-purpose: button + external connector |
| BTN8 | LIM6 | 51 | Dual-purpose: button + external connector |
| BTN9 | LIM7 | 52 | Dual-purpose: button + external connector |
| BTN10 | LIM8 | 53 | Dual-purpose: button + external connector |

All inputs use `INPUT_PULLUP` — they read HIGH when not activated and LOW when pressed or triggered.

The voltage supplied to the external limit switch connectors is selected globally by the `JP_LIM_V` jumper:
- **Position 1-2:** 5V (default; suits mechanical switches and most optical endstops)
- **Position 2-3:** 3.3V (for low-voltage Hall effect or proximity sensors)

Limit switches can be assigned to stepper motors or DC motors for homing in `config.h`:

```c
#define PIN_ST1_LIMIT   PIN_LIM1  // Stepper 1 homing switch
#define PIN_M1_LIMIT    PIN_LIM5  // DC motor 1 homing switch
```

> **Caution:** Because buttons and limit switches share the same pins, do not press on-board buttons while the firmware is using those pins for limit-switch homing. Account for this in any custom firmware logic that reads button or limit-switch state.

### 3.8 Status and User LEDs

| LED | Color | Pin | PWM | Firmware function |
|-----|---|-----|-----|---|
| LED1 | Green | 44 | Yes | System OK / user-controlled |
| LED2 | Red | 5 | Yes | Error / low battery |
| LED3 | Blue | 45 | Yes | User-controlled (exposed) |
| LED4 | Orange | 46 | Yes | User-controlled (exposed) |
| LED5 | Purple | 47 | No | User-controlled (exposed) |
| NeoPixel | RGB | 42 | — | Automatic system-state indicator |

> **Note:** LED5 (pin 47) is digital ON/OFF only. LED2 (pin 5) supports PWM and animated dimming via the firmware LED controller.

The **NeoPixel** (WS2812B) on pin 42 automatically reflects the firmware system state and is not user-controlled. An extension socket (`J_NEOPIXEL`) allows external RGB strips to share the same data line.

### 3.9 I2C and Qwiic Connectors

| Connector | Bus | Voltage | Location |
|---|-----|---|---|
| J_QWIIC_1 – J_QWIIC_4 | Arduino I2C (pins 20/21) | 3.3V (level-shifted) | Arduino side |
| J_QWIIC_RPI1, J_QWIIC_RPI2 | RPi I2C1 (GPIO2/GPIO3) | 3.3V (native) | RPi side |

The Arduino-side Qwiic connectors use a TXS0102 level shifter (5V ↔ 3.3V). All four Arduino Qwiic connectors are on the same I2C bus and are fully compatible with the standard Qwiic/STEMMA QT pinout:

| Pin | Color | Signal |
|-----|---|---|
| 1 | Black | GND |
| 2 | Red | 3.3V |
| 3 | Blue | SDA |
| 4 | Yellow | SCL |

The RPi-side Qwiic connectors are a completely separate bus from the Arduino-side connectors. Sensors intended for ROS2 use (lidar, ultrasonic) should connect to the RPi-side connectors. Sensors intended for the Arduino firmware (IMU) connect to the Arduino-side connectors.

---

## 4. NUEVO UI

### 4.1 Overview

The NUEVO UI is a web-based interface for teleoperation, monitoring, and configuration. It consists of two components:

- **nuevo_bridge** — a Python backend (`nuevo_ui/backend/nuevo_bridge`) that owns the serial connection to the Arduino, decodes TLV packets, and serves a FastAPI + WebSocket API
- **Frontend** — a React/TypeScript single-page application (`nuevo_ui/frontend`) that connects to the bridge via WebSocket

The bridge can run in two modes:
- **Plain Python mode** — standalone, no ROS2 required; accessed via browser only
- **ROS mode** — the same bridge runtime also publishes/subscribes to ROS2 topics; see [Section 6](#6-software--ros2-nodes)

### 4.2 Starting the Bridge

The recommended workflow uses Docker:

**Build the frontend first** (required once, or after any frontend changes):

```bash
cd nuevo_ui/frontend
npm install
npm run build
cd ../..
cp -r nuevo_ui/frontend/dist/. nuevo_ui/backend/static/
```

**On the Raspberry Pi (with hardware):**

```bash
docker compose -f ros2_ws/docker/docker-compose.rpi.yml build
docker compose -f ros2_ws/docker/docker-compose.rpi.yml up
```

**On macOS/Windows (mock bridge, no hardware needed):**

```bash
docker compose -f ros2_ws/docker/docker-compose.vm.yml build
docker compose -f ros2_ws/docker/docker-compose.vm.yml up
```

The UI will be available at `http://localhost:8000` (or the RPi's IP on the real hardware).

### 4.3 UI Overview

The web interface provides the following panels:

- **System State** — displays the current firmware state (IDLE, RUNNING, ERROR, ESTOP) and battery/5V/servo rail voltages; contains the START, STOP, RESET, and ESTOP buttons
- **DC Motor Control** — per-motor velocity, position, or PWM setpoints; live encoder tick count and speed readback; enable/disable toggles
- **Stepper Control** — per-motor target position, speed, and enable toggles; homing trigger
- **Servo Control** — per-channel angle or pulse-width sliders (channels 0–15)
- **Sensors** — IMU orientation (roll/pitch/yaw), acceleration, gyroscope; odometry position (x, y, θ); voltage monitoring
- **I/O** — button/limit switch states; LED output controls
- **Magnetometer Calibration** — start/stop calibration sampling, save to persistent storage

### 4.4 Odometry

The firmware computes differential-drive odometry from the two designated wheel motor encoders. The defaults come from `config.h` and can be overridden at runtime with `SYS_ODOM_PARAM_SET`:

```c
#define ODOM_LEFT_MOTOR   0    // DC motor index (0-based) for left wheel
#define ODOM_RIGHT_MOTOR  1    // DC motor index (0-based) for right wheel
#define WHEEL_DIAMETER_MM 74.0f
#define WHEEL_BASE_MM     333.0f
```

Odometry is updated in the 100 Hz sensor task and streamed to the bridge as `SENSOR_KINEMATICS` telemetry. The coordinate frame follows the right-hand 2D convention: **+X is forward, +Y is left**. Initial heading `θ` defaults to 90° (facing the +Y axis) and can be overridden either with `INITIAL_THETA` in `config.h` or at runtime with `SYS_ODOM_PARAM_SET`.

`SYS_ODOM_RESET` resets the pose to `(0, 0, current initial theta)`. `SYS_ODOM_PARAM_SET` updates wheel geometry and left/right odom wheel mapping without overwriting the current pose.

To inspect the current runtime odometry configuration, the bridge can send `SYS_ODOM_PARAM_REQ` and read back `SYS_ODOM_PARAM_RSP`. The response reports the active wheel diameter, wheel base, initial heading, left/right odom motors, and per-side direction inversion flags.

---

## 5. Firmware

### 5.1 Prerequisites

- **Arduino IDE 2.x** (or arduino-cli)
- **Arduino AVR Boards core** installed in the IDE (Boards Manager → search "Arduino AVR Boards")
- **Board target:** Arduino Mega or Mega 2560

**Required: serial buffer size configuration**

The stock AVR serial buffers are too small for the high-rate UART link to the Raspberry Pi. This must be set before the first build or you will see UART overrun errors at runtime.

Create (or edit) `platform.local.txt` in your Arduino AVR core directory:

```text
compiler.cpp.extra_flags=-DSERIAL_RX_BUFFER_SIZE=512 -DSERIAL_TX_BUFFER_SIZE=256
```

Typical locations:

| OS | Path |
|----|---|
| Windows | `C:\Users\<user>\AppData\Local\Arduino15\packages\arduino\hardware\avr\<version>\platform.local.txt` |
| macOS | `~/Library/Arduino15/packages/arduino/hardware/avr/<version>/platform.local.txt` |
| Linux | `~/.arduino15/packages/arduino/hardware/avr/<version>/platform.local.txt` |

If the Arduino AVR Boards version changes, verify the file still exists under the new versioned directory.

### 5.2 Build and Upload

**Arduino IDE:**

1. Open `firmware/arduino/arduino.ino`
2. Select board: `Arduino Mega or Mega 2560`
3. Select the correct port (the Arduino's USB-B port)
4. Click **Verify** to build
5. Click **Upload**

**arduino-cli (optional):**

```bash
arduino-cli compile --fqbn arduino:avr:mega firmware/arduino
arduino-cli upload --fqbn arduino:avr:mega -p /dev/ttyUSB0 firmware/arduino
```

Replace `/dev/ttyUSB0` with the correct port for your OS (e.g. `/dev/cu.usbmodem...` on macOS, `COM3` on Windows).

### 5.3 Key Configuration (`config.h`)

All user-facing compile-time settings are in `firmware/arduino/src/config.h`. The most commonly adjusted settings are:

**Robot geometry** — defaults that must match your physical robot unless you override them at runtime:

```c
#define WHEEL_DIAMETER_MM   74.0f    // outer diameter of drive wheels (mm)
#define WHEEL_BASE_MM       333.0f   // center-to-center track width (mm)
#define ODOM_LEFT_MOTOR     0        // DC motor index for left wheel (0-based)
#define ODOM_RIGHT_MOTOR    1        // DC motor index for right wheel (0-based)
```

**Battery type** — prevents over-discharge and sets voltage warning thresholds:

```c
#define BATTERY_TYPE    BATTERY_NIMH_10CELL  // change to match your battery
// Options: BATTERY_NIMH_8CELL, BATTERY_NIMH_10CELL,
//          BATTERY_LIPO_2S through BATTERY_LIPO_6S, BATTERY_CUSTOM
```

**Encoder direction** — set to 1 if positive motor PWM produces a negative encoder count:

```c
#define ENCODER_1_DIR_INVERTED  0
#define ENCODER_2_DIR_INVERTED  0
#define ENCODER_3_DIR_INVERTED  1
#define ENCODER_4_DIR_INVERTED  1
```

**Motor direction** — set to 1 if the H-bridge wiring makes the motor spin backwards:

```c
#define DC_MOTOR_1_DIR_INVERTED 1
#define DC_MOTOR_2_DIR_INVERTED 1
```

See [Appendix A](#appendix-a-configh-quick-reference) for a full table of tunable settings.

### 5.4 Firmware Architecture

The firmware uses a two-tier scheduling architecture:

**Hard real-time ISRs** (interrupts — unaffected by anything in `loop()`):

| ISR | Rate | Purpose |
|-----|---|---|
| Encoder INT/PCINT | edge-driven | count quadrature encoder transitions |
| TIMER1_OVF_vect | 800 Hz | DC motor latch/apply (one motor per tick, 200 Hz per motor) |
| TIMER3_OVF_vect | 10 kHz | stepper pulse generation |

**Soft tasks** (millis-based, run in `loop()`, can be preempted by ISRs):

| Task | Rate | Purpose |
|---|---|---|
| taskUART | 100 Hz | UART RX/TX service, heartbeat, telemetry packing |
| taskMotorFeedback | 200 Hz | refresh encoder-derived position/velocity cache |
| taskSafety | 100 Hz | heartbeat timeout and battery fault evaluation |
| taskSensors | 100 Hz | IMU, voltage monitoring, button/limit sampling |
| taskUserIO | 20 Hz | LED animations, NeoPixel rendering |

This separation ensures that PID and stepper timing are never delayed by slow tasks like I2C reads or TLV parsing. No I2C, UART, or EEPROM operations are allowed inside ISR handlers.

For deeper reading, see [firmware/docs/architecture.md](../../firmware/docs/architecture.md).

---

## 6. Software — ROS2 Nodes

### 6.1 Overview

The ROS2 workspace (`ros2_ws/`) runs on the Raspberry Pi and provides a ROS-native interface to the robot. It is built on the same `nuevo_bridge` Python runtime used by the web UI, so the UI and ROS always share the same decoded firmware state and command path.

**When running in ROS mode, a single integrated process owns:**
- one serial connection to the Arduino
- one TLV decode pipeline
- one FastAPI/WebSocket UI server
- one ROS node

This prevents the serial port from being opened twice.

### 6.2 Package Structure

```
ros2_ws/src/
├── bridge_interfaces/   # Custom ROS message and service definitions
├── bridge/              # ROS wrapper node around the nuevo_bridge runtime
├── robot/               # Main robot logic, launch files, URDF, RViz config
├── sensors/             # RPi-connected sensor nodes (lidar, ultrasonic)
└── vision/              # Camera and perception pipeline
```

The shared Python runtime lives outside `ros2_ws`:

```
nuevo_ui/backend/nuevo_bridge/   # Transport, TLV codec, web backend
```

### 6.3 Raspberry Pi Setup

**Enable UART on the Pi 5:**

Edit `/boot/firmware/config.txt` and add:

```
enable_uart=1
dtoverlay=uart0-pi5
```

Edit `/boot/firmware/cmdline.txt` and remove any `console=serial0,...` or `console=ttyAMA0,...` entries, then reboot.

Verify the UART device is present:

```bash
ls -l /dev/ttyAMA0
```

The bridge expects `/dev/ttyAMA0` at **200,000 baud**.

### 6.4 Starting the ROS Bridge (Docker — Recommended)

Build the frontend once before starting (see [Section 4.2](#42-starting-the-bridge)).

**On the Raspberry Pi:**

```bash
docker compose -f ros2_ws/docker/docker-compose.rpi.yml build
docker compose -f ros2_ws/docker/docker-compose.rpi.yml up
```

**On macOS/Windows (mock bridge):**

```bash
docker compose -f ros2_ws/docker/docker-compose.vm.yml build
docker compose -f ros2_ws/docker/docker-compose.vm.yml up
```

Useful Docker commands:

```bash
docker compose -f <compose-file> down          # stop the stack
docker compose -f <compose-file> build         # rebuild after dependency changes
docker compose -f <compose-file> down -v       # clean build cache
docker compose -f <compose-file> logs -f       # stream logs
```

### 6.5 Key ROS Topics and Services

Topics follow the same lowercase snake_case naming as the TLV protocol:

| Topic | Direction | Description |
|---|---|---|
| `/sys_state` | publish | firmware system state and timestamps |
| `/sys_power` | publish | battery, 5V, servo rail voltages |
| `/dc_state_all` | publish | all DC motor positions, velocities, PWM |
| `/step_state_all` | publish | all stepper positions and states |
| `/sensor_imu` | publish | IMU orientation, acceleration, gyroscope |
| `/sensor_kinematics` | publish | odometry: x, y, θ |
| `/dc_set_velocity` | subscribe | set DC motor target velocity (ticks/s) |
| `/dc_set_pwm` | subscribe | set DC motor direct PWM |
| `/set_firmware_state` | service | transition firmware state (IDLE/RUNNING/ESTOP) |

Example commands:

```bash
# Transition to RUNNING state (2)
ros2 service call /set_firmware_state bridge_interfaces/srv/SetFirmwareState "{target_state: 2}"

# Set motor 1 velocity to 200 ticks/s
ros2 topic pub --once /dc_set_velocity bridge_interfaces/msg/DCSetVelocity \
  "{motor_number: 1, target_ticks: 200}"

# Monitor odometry
ros2 topic echo /sensor_kinematics
```

### 6.6 Manual Shell Workflow (without Docker autostart)

```bash
docker compose -f ros2_ws/docker/docker-compose.rpi.yml run --rm --entrypoint bash robot

# Inside the container:
source /opt/ros/jazzy/setup.bash
colcon build --symlink-install --cmake-args -DBUILD_TESTING=OFF
source install/setup.bash
ros2 run bridge bridge
```

### 6.7 Native Ubuntu 24.04 (without Docker)

```bash
cd ros2_ws
source /opt/ros/jazzy/setup.bash
export NUEVO_BRIDGE_SOURCE="$(pwd)/../nuevo_ui/backend"
colcon build --symlink-install
source install/setup.bash
ros2 run bridge bridge
```

---

## 7. Sensors and I2C Devices

### 7.1 IMU (ICM-20948)

The ICM-20948 is a 9-DoF IMU (accelerometer + gyroscope + magnetometer) connected to the Arduino's I2C bus via a Qwiic connector.

- **I2C address:** 0x69 (AD0 pin HIGH; `IMU_AD0_VAL = 1` in `config.h`)
- **Update rate:** 25 Hz (alternating raw read and Fusion update each at 100 Hz task rate)
- **Fusion library:** Madgwick-based AHRS (`lib/Fusion`)
  - 6-DoF mode (accel + gyro) when magnetometer is uncalibrated
  - 9-DoF mode (accel + gyro + mag) when valid magnetometer calibration is stored
- **Output:** roll, pitch, yaw (degrees); raw acceleration (g); raw gyroscope (dps)
- **Full-scale settings:** ±2g accelerometer, ±250 dps gyroscope (configured in `config.h`)

The IMU must be on an **Arduino-side Qwiic connector** (J_QWIIC_1 through J_QWIIC_4), not the RPi-side connectors.

### 7.2 Magnetometer Calibration

Without magnetometer calibration, the IMU runs in 6-DoF mode and yaw will drift over time. Calibration collects hard-iron offset samples while the robot is rotated through all orientations, then saves them to EEPROM.

**Calibration procedure:**

1. Open the NUEVO UI and navigate to the **Magnetometer Calibration** panel (or use the bridge API / ROS topic)
2. Click **Start Calibration**
3. Rotate the robot slowly through all orientations — roll it, pitch it, and yaw it in full circles — for at least 10–20 seconds (minimum 50 samples required, set by `MAG_CAL_MIN_SAMPLES`)
4. Click **Save Calibration** — offsets are saved to EEPROM and will reload automatically on next boot
5. To clear a saved calibration, click **Clear Calibration**

Calibration is persistent across power cycles. If the robot's magnetic environment changes significantly (e.g. new metal chassis, different mounting location), redo the calibration.

### 7.3 Voltage Monitoring

The firmware samples three voltage rails at 10 Hz via the Arduino ADC:

| Rail | Pin | Divider | Measured range |
|---|-----|---|---|
| Battery (VBAT) | A0 | 1:6 (50kΩ/10kΩ) | ~0–30V |
| 5V rail | A1 | 1:2 | ~0–10V |
| Servo rail (VSERVO) | A2 | 1:3 | ~0–15V |

Battery thresholds (configurable via `BATTERY_TYPE` in `config.h`):
- **Warning threshold:** NeoPixel turns yellow, fault flag set in telemetry
- **Cutoff threshold:** all motors disabled (same effect as heartbeat loss)
- **Minimum present threshold (2.0V):** below this voltage all actuator enable commands are silently rejected — prevents operation with no battery connected

### 7.4 Adding Qwiic Devices

To add a custom I2C sensor:

1. Connect to any available Arduino-side Qwiic connector (J_QWIIC_1 through J_QWIIC_4)
2. Verify the sensor's I2C address does not conflict with existing devices:
   - IMU: 0x69
   - PCA9685: 0x40 (default)
3. Add a driver in `firmware/arduino/src/drivers/` and register it in `SensorManager`
4. I2C access **must not** occur inside any ISR — only in soft-task context (e.g. inside `SensorManager::tick()`)

For sensors intended for use with ROS2 only (lidar, ultrasonic), connect to the RPi-side Qwiic connectors (J_QWIIC_RPI1/RPI2) instead and implement the driver in `ros2_ws/src/sensors/`.

---

## 8. Communication Protocol

The Arduino and Raspberry Pi communicate over UART (Serial2) using a compact TLV (Type-Length-Value) framing protocol.

**Physical layer:**
- UART Serial2, pins 16 (TX) and 17 (RX) on the Arduino
- GPIO14/15 on the Raspberry Pi
- 5V ↔ 3.3V level shifting on the board
- Default baud rate: **200,000 bps**
- Serial port: `/dev/ttyAMA0` on the Pi

**Protocol version:** v4

**Message types** are grouped into families:

| Family | Examples | Direction |
|---|---|---|
| System | `SYS_HEARTBEAT`, `SYS_STATE`, `SYS_POWER` | bidirectional |
| DC Motors | `DC_ENABLE`, `DC_SET_VELOCITY`, `DC_STATE_ALL` | RPi→Arduino (cmd), Arduino→RPi (telemetry) |
| Steppers | `STEP_ENABLE`, `STEP_SET`, `STEP_STATE_ALL` | bidirectional |
| Servos | `SERVO_ENABLE`, `SERVO_SET`, `SERVO_STATE_ALL` | bidirectional |
| Sensors | `SENSOR_IMU`, `SENSOR_KINEMATICS`, `SENSOR_MAG_CAL_CMD` | bidirectional |
| User I/O | `IO_SET_LED`, `IO_INPUT_STATE`, `IO_OUTPUT_STATE` | bidirectional |

The bridge must send a `SYS_HEARTBEAT` at least every 500 ms (`HEARTBEAT_TIMEOUT_MS`) or the firmware will disable all actuators. Motors re-enable automatically when the heartbeat resumes.

For complete message field layouts and byte sizes, see:
- [`docs/COMMUNICATION_PROTOCOL.md`](../COMMUNICATION_PROTOCOL.md) — logical design, semantics, streaming policy
- [`tlv_protocol/TLV_Payloads.md`](../../tlv_protocol/TLV_Payloads.md) — exact wire payload format for every message type

---

## 9. Safety and Fault Handling

### 9.1 Firmware State Machine

The firmware moves through a defined set of states. Only `SystemManager` may perform state transitions; other modules report faults and intent.

```
           power-on
               │
           [INIT]
               │  boot complete
           [IDLE]  ◄──────────────────────────────────────────┐
               │  START command received                      │ RESET command
           [RUNNING]                                          │
               │                                              │
       ┌───────┴───────┐                                      │
       │               │                                      │
  fault detected   STOP command                               │
       │               │                                      │
     [ERROR]        [IDLE]                               [ERROR / ESTOP]
       │                                                      ▲
       │ RESET command                               ESTOP command (any state)
       └─────────────────────────────────────────────► [ESTOP]
```

| State | Motors allowed | What can change it |
|---|---|---|
| INIT | No | Boot completion |
| IDLE | No (enable commands accepted but not activated) | START command |
| RUNNING | Yes | STOP, fault, ESTOP |
| ERROR | No | RESET command |
| ESTOP | No | RESET command |

### 9.2 Heartbeat Timeout

The firmware expects a valid TLV packet from the bridge at least once every `HEARTBEAT_TIMEOUT_MS = 500 ms`. If no packet is received within this window:

- All DC motors are immediately disabled (PWM set to 0)
- All stepper motors are disabled
- The firmware remains in RUNNING state (it does not transition to ERROR)
- Motors re-enable automatically when the heartbeat is restored and the firmware receives a new enable command

The `SYS_HEARTBEAT` message is the dedicated keepalive, but any valid TLV packet also refreshes the timer.

### 9.3 Battery Voltage Thresholds

Battery thresholds are set by `BATTERY_TYPE` in `config.h`. The defaults for a 10-cell NiMH:

| Threshold | Value | Effect |
|---|---|---|
| `VBAT_WARN_V` | 10.5V | Warning flag in telemetry, NeoPixel turns yellow |
| `VBAT_CUTOFF_V` | 10.0V | All motors disabled, same as heartbeat loss |
| `VBAT_OVERVOLTAGE_V` | 15.5V | Warning flag in telemetry (wrong charger or wrong chemistry) |
| `VBAT_MIN_PRESENT_V` | 2.0V | Below this: all actuator enables silently rejected |

To use a different battery, change `BATTERY_TYPE` to one of: `BATTERY_NIMH_8CELL`, `BATTERY_NIMH_10CELL`, `BATTERY_LIPO_2S` through `BATTERY_LIPO_6S`, or `BATTERY_CUSTOM`.

### 9.4 ESTOP

ESTOP immediately disables all actuators and transitions the firmware to the ESTOP state from any other state. It is triggered by:

- the `SYS_ESTOP` TLV command from the bridge or UI
- the ESTOP button in the NUEVO UI
- (optionally) a ROS service call

To recover from ESTOP, send a `SYS_RESET` command. The firmware will return to IDLE state. Motors must be re-enabled and a START command issued before motion can resume.

### 9.5 NeoPixel System State Colors

The on-board WS2812B NeoPixel (pin 42) automatically reflects the current firmware and safety state. Refer to the firmware source (`UserIO`) for the exact color mapping, which may be updated across firmware versions.

### 9.6 USB Debug Output

The Arduino emits human-readable status messages over the USB serial port (Serial0) at 115200 baud. This output is useful for firmware bring-up and debugging.

Startup banner and periodic `[SYSTEM]`, `[TIMING]`, `[UART]`, and `[SENSORS]` lines are emitted when `STATUS_REPORTER_ENABLED = 1` in `config.h` (disabled by default to reduce serial traffic). Fault events (motor faults, UART errors, PID overruns) are always logged when they occur.

Open the Arduino IDE Serial Monitor at 115200 baud to view this output.

---

## 10. Troubleshooting

### Power Issues

**No LEDs when power switch is ON:**
- Check that the blade fuse is not blown (visual inspection; replace with 15A if blown)
- Measure battery voltage at the XT60 connector — should be within the rated range
- Verify the power switch is fully engaged

**5V LED is off but battery is present:**
- The 5V buck converter may have shut down from overcurrent or thermal protection
- Disconnect all loads (unplug the RPi, H-bridge modules) and power-cycle
- If the 5V LED still does not illuminate after removing all loads, the buck converter may be damaged

**Power-good LED off or flickering:**
- OFF: board is running from RPi USB-C backfeed only — the buck converter is not active (normal during USB-C development)
- Flickering: possible voltage instability on the 5V rail; check for overload or loose connections

---

### Motor Issues

**DC motors not moving:**
- Confirm the firmware is in RUNNING state (check the UI system state indicator)
- Verify the motor has been enabled via `DC_ENABLE` command
- Check H-bridge module power connections (V+ from the battery rail, GND)
- Measure the EN pin with a multimeter — should show a PWM waveform when a speed command is active
- Test the motor directly with a bench supply to rule out a failed motor

**Encoders not counting:**
- Check encoder power (5V and GND at the encoder connector)
- Verify A and B wires are connected to the correct 4-pin encoder header pins
- Use an oscilloscope to confirm the encoder generates transitions when the shaft turns
- Check that `ENCODER_N_DIR_INVERTED` is set correctly in `config.h`

**Steppers not moving:**
- Verify the driver module is fully seated in its socket
- Check that the EN jumper under the driver is installed
- Confirm the motor coil wires (A+, A−, B+, B−) are in the correct order — swapping a coil pair is the most common wiring error
- Measure the STEP pin with an oscilloscope — should show pulses when a move is commanded
- Ensure the driver's VMOT pin has battery voltage

**Servos not responding:**
- Confirm `SERVO_CONTROLLER_ENABLED = 1` in `config.h` and that the PCA9685 was detected at boot (check USB debug output for `PCA9685 initialized`)
- Verify the I2C connection between the main PCB header and the PCA9685 module
- Check `JP_SERVO_PWR` is closed if using on-board servo power, or that external servo power is connected if the jumper is open
- Measure SERVO_VOUT at the servo rail with a multimeter

---

### Communication Issues

**NUEVO UI shows "Disconnected" or no data:**
- Verify the bridge is running (`docker compose logs -f` or check the terminal)
- Confirm the serial port is correct: the bridge expects `/dev/ttyAMA0` on the RPi
- Confirm UART is enabled on the Pi (see [Section 6.3](#63-raspberry-pi-setup))
- Verify the baud rate: both sides must be at 200,000 bps

**Arduino–Raspberry Pi UART errors (DOR/FE in USB debug output):**
- DOR (data overrun) or FE (framing error) messages indicate the Arduino UART buffer is overflowing
- Confirm `platform.local.txt` is set with `SERIAL_RX_BUFFER_SIZE=512` (see [Section 5.1](#51-prerequisites))
- Confirm the firmware was compiled and uploaded after adding `platform.local.txt`

**I2C device not detected:**
- Run an I2C scanner sketch to check the address
- Verify the device is on the correct bus (Arduino-side vs. RPi-side Qwiic connectors)
- Check pull-up resistors: idle SDA/SCL lines should read ~2.5–3.3V

---

### LED and Button Issues

**User buttons not responding:**
- Verify `INPUT_PULLUP` is set in firmware; pins should read HIGH at idle and LOW when pressed
- Measure the pin voltage with a multimeter (≈5V idle, ≈0V when pressed)

**Limit switches triggering unexpectedly:**
- Check that `JP_LIM_V` is set to the voltage matching your sensor (5V or 3.3V)
- Verify the switch type: normally-open switches should be open (HIGH) at rest with INPUT_PULLUP

**LED_PURPLE not dimming:**
- LED_PURPLE is digital only — use ON/OFF control only.

---

### Thermal Issues

**Buck converters hot:**
- 60–80°C under load is normal
- Above ~100°C indicates a problem: reduce load, add heatsinks to converter ICs, verify ventilation
- Do not cover the buck converter ICs with wiring or other components

---

## Appendix A: config.h Quick Reference

The full configuration file is at `firmware/arduino/src/config.h`. The most commonly adjusted settings:

| Setting | Default | What it controls |
|---|---|---|
| `WHEEL_DIAMETER_MM` | 74.0 | Drive wheel outer diameter (mm) |
| `WHEEL_BASE_MM` | 333.0 | Wheel center-to-center track width (mm) |
| `ODOM_LEFT_MOTOR` | 0 | DC motor index used as left wheel (0-based) |
| `ODOM_RIGHT_MOTOR` | 1 | DC motor index used as right wheel (0-based) |
| `ODOM_LEFT_MOTOR_DIR_INVERTED` | 0 | Flip sign of left wheel odometry ticks |
| `ODOM_RIGHT_MOTOR_DIR_INVERTED` | 1 | Flip sign of right wheel odometry ticks |
| `BATTERY_TYPE` | `BATTERY_NIMH_10CELL` | Battery chemistry and voltage thresholds |
| `ENCODER_PPR` | 1440 | Encoder pulses per revolution (spec sheet value) |
| `ENCODER_N_MODE` | `ENCODER_4X` | Counting mode per motor (ENCODER_2X or ENCODER_4X) |
| `ENCODER_N_DIR_INVERTED` | 0 or 1 | Flip encoder count direction per motor |

The `ODOM_*` defaults above are also writable at runtime through `SYS_ODOM_PARAM_SET`. The lower-level `DC_MOTOR_*_DIR_INVERTED` and `ENCODER_*_DIR_INVERTED` settings remain compile-time motor/encoder configuration.
| `DC_MOTOR_N_DIR_INVERTED` | 1 | Flip H-bridge direction polarity per motor |
| `HEARTBEAT_TIMEOUT_MS` | 500 | ms without a packet before motors are disabled |
| `RPI_BAUD_RATE` | 200000 | UART baud rate to Raspberry Pi |
| `ENCODER_STALL_DETECTION` | 0 | Enable stall detection (0=off, 1=on) |
| `IMU_AD0_VAL` | 1 | IMU I2C address select (0=0x68, 1=0x69) |
| `SERVO_CONTROLLER_ENABLED` | 1 | Enable PCA9685 servo controller |
| `STATUS_REPORTER_ENABLED` | 0 | Enable periodic status on USB serial |
| `DEBUG_PINS_ENABLED` | 0 | Enable oscilloscope debug pins (A7–A13) |
| `DEFAULT_VEL_KP/KI/KD` | 0.2 / 4.0 / 0.0 | Default velocity PID gains |
| `DEFAULT_POS_KP/KI/KD` | 5.0 / 0.0 / 0.5 | Default position PID gains |
| `FUSION_GAIN` | 0.2 | Madgwick AHRS convergence gain |

---

## Appendix B: Pin Table (Rev. B)

For the complete Rev. B GPIO table with timer/register assignments, see:
- [`firmware/arduino/src/pins.h`](../../firmware/arduino/src/pins.h)
- [`firmware/docs/pin_table_rev_B.md`](../../firmware/docs/pin_table_rev_B.md)

Summary of major pin groups:

| Group | Pins |
|---|---|
| USB Serial (Serial0) | 0 (RX), 1 (TX) |
| RPi UART (Serial2) | 16 (TX), 17 (RX) |
| I2C | 20 (SDA), 21 (SCL) |
| M1 encoder | 2 (A, INT0), 3 (B, INT1) |
| M2 encoder | 18 (A, INT5), 19 (B, INT4) |
| M3 encoder | A14 (A, PCINT22), A15 (B, PCINT23) |
| M4 encoder | 11 (A, PCINT5), 12 (B, PCINT6) |
| M1 PWM/dir | 6 (EN), 8 (IN1), 43 (IN2) |
| M2 PWM/dir | 7 (EN), 4 (IN1), 30 (IN2) |
| M3 PWM/dir | 9 (EN), 34 (IN1), 35 (IN2) |
| M4 PWM/dir | 10 (EN), 36 (IN1), 37 (IN2) |
| Stepper 1 | 14 (STEP), 22 (DIR), 26 (EN) |
| Stepper 2 | 15 (STEP), 23 (DIR), 27 (EN) |
| Stepper 3 | 32 (STEP), 24 (DIR), 28 (EN) |
| Stepper 4 | 33 (STEP), 25 (DIR), 29 (EN) |
| LEDs | 5 (RED), 44 (GREEN), 45 (BLUE), 46 (ORANGE), 47 (PURPLE) |
| NeoPixel | 42 |
| Buttons 1–2 | 38, 39 |
| Buttons 3–10 / Limit 1–8 | 40, 41, 48, 49, 50, 51, 52, 53 |
| Battery sense | A0 |
| 5V sense | A1 |
| Servo sense | A2 |
| Motor current sense | A3 (M1), A4 (M2), A5 (M3), A6 (M4) |

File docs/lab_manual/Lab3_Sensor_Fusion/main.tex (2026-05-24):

\documentclass[12pt,letterpaper]{article}

% ─── Packages ──────────────────────────────────────────────────────────────────
\usepackage[margin=1in]{geometry}
\usepackage{hyperref}
\usepackage{graphicx}
\usepackage{float}
\usepackage{booktabs}
\usepackage{tabularx}
\usepackage{enumitem}
\usepackage{amsmath}
\usepackage{amssymb}
\usepackage{listings}
\usepackage{xcolor}
\usepackage{tcolorbox}
\usepackage{fancyhdr}
\usepackage{titlesec}
\usepackage{caption}
\usepackage{subcaption}
\usepackage{microtype}
\usepackage{parskip}
\usepackage{tikz}
\usetikzlibrary{arrows.meta,positioning,shapes.geometric}

% ─── Code listing style ────────────────────────────────────────────────────────
\usepackage{textcomp} % Required for the upquote option

\lstset{
    basicstyle=\ttfamily,
    columns=fullflexible,
    keepspaces=true,
    upquote=true
}

\lstdefinestyle{python}{
  language=Python,
  basicstyle=\ttfamily\small,
  keywordstyle=\color{blue}\bfseries,
  commentstyle=\color{gray}\itshape,
  stringstyle=\color{orange!80!black},
  numberstyle=\tiny\color{gray},
  numbers=left,
  stepnumber=1,
  breaklines=true,
  frame=single,
  backgroundcolor=\color{gray!5},
  showstringspaces=false,
  tabsize=4,
  captionpos=b,
}

\lstdefinestyle{cpp}{
  language=C++,
  basicstyle=\ttfamily\small,
  keywordstyle=\color{blue}\bfseries,
  commentstyle=\color{gray}\itshape,
  stringstyle=\color{orange!80!black},
  numberstyle=\tiny\color{gray},
  numbers=left,
  stepnumber=1,
  breaklines=true,
  frame=single,
  backgroundcolor=\color{gray!5},
  showstringspaces=false,
}

\lstdefinestyle{bash}{
  language=bash,
  basicstyle=\ttfamily\small,
  keywordstyle=\color{teal}\bfseries,
  commentstyle=\color{gray}\itshape,
  breaklines=true,
  frame=single,
  backgroundcolor=\color{black!3},
  showstringspaces=false,
}

\lstdefinestyle{json}{
  basicstyle=\ttfamily\small,
  breaklines=true,
  frame=single,
  backgroundcolor=\color{black!3},
  showstringspaces=false,
}

% ─── Callout boxes ─────────────────────────────────────────────────────────────
\tcbuselibrary{skins,breakable}

\newtcolorbox{notebox}{
  colback=blue!5, colframe=blue!60!black,
  title=Note, fonttitle=\bfseries, breakable
}

\newtcolorbox{warningbox}{
  colback=yellow!10, colframe=orange!80!black,
  title=Warning, fonttitle=\bfseries, breakable
}

\newtcolorbox{taskbox}[1]{
  colback=green!5, colframe=green!50!black,
  title=#1, fonttitle=\bfseries, breakable
}

% ─── Header / Footer ──────────────────────────────────────────────────────────
\pagestyle{fancy}
\fancyhf{}
\rhead{Week 3: Sensor Fusion}
\lhead{MAE 162E}
\rfoot{Page \thepage}

% ─── Section formatting ────────────────────────────────────────────────────────
\titleformat{\section}{\large\bfseries}{}{0em}{\thesection\quad}
\titleformat{\subsection}{\normalsize\bfseries}{}{0em}{\thesubsection\quad}

% ─── Hyperref setup ────────────────────────────────────────────────────────────
\hypersetup{
  colorlinks=true,
  linkcolor=blue!60!black,
  urlcolor=blue!60!black,
  citecolor=green!50!black,
}

% ─── Placeholder command for diagrams ─────────────────────────────────────────
\newcommand{\diagramplaceholder}[2][4cm]{%
  \begin{center}
    \fbox{\begin{minipage}{0.85\textwidth}
      \vspace{#1}
      \centering\textit{[Diagram: #2]}
      \vspace{#1}
    \end{minipage}}
  \end{center}
}

% ═══════════════════════════════════════════════════════════════════════════════
\begin{document}
% ═══════════════════════════════════════════════════════════════════════════════

% ─── Title ────────────────────────────────────────────────────────────────────
\begin{titlepage}
  \centering
  \vspace*{2cm}
  {\Huge\bfseries MAE 162E Capstone\par}
  \vspace{0.5cm}
  {\LARGE Week 3: Sensor Fusion\par}
  \vspace{0.5cm}
  {\large Integrating IMU and ArUco-Based GPS\\for Robust Pose Estimation\par}
  \vfill
  {\small Version 1.0 \quad|\quad \today}
\end{titlepage}

\tableofcontents
\newpage

% ═══════════════════════════════════════════════════════════════════════════════
% MATERIALS LIST
% ═══════════════════════════════════════════════════════════════════════════════
\section*{Materials}
\addcontentsline{toc}{section}{Materials}

Each group will receive the following items from the course staff.
Check that all items are present before beginning the lab.

\begin{itemize}[leftmargin=2em]
  \item \textbf{ICM-20948 IMU breakout board} (SparkFun DEV-15335 or equivalent)
        --- 9 degrees of freedom: 3-axis accelerometer, 3-axis gyroscope, 3-axis
        magnetometer.
  \item \textbf{I\textsuperscript{2}C wire assembly} --- 4-conductor jumper cable
        (VCC, GND, SDA, SCL). Length: approx.\ 20~cm.
  \item \textbf{Printed ArUco tag} --- Tags are distributed by course staff;
        each group receives a \emph{unique} tag ID (IDs 11--18, 4X4\_50
        dictionary, printed at 10~cm~$\times$~10~cm).
        Do \emph{not} swap tags with another group.
        Once you receive your tag, set \texttt{TAG\_ID} at the top of
        \texttt{main.py} to match your assigned ID:
\begin{lstlisting}[style=python]
TAG_ID = 11   # replace with your group's assigned tag ID
\end{lstlisting}
\end{itemize}

% \begin{notebox}
%   The Arduino Mega 2560, Raspberry Pi~5, power board, and chassis are already
%   assembled on your robot. You only need to wire the IMU and mount your ArUco
%   tag.
% \end{notebox}

\newpage

% ═══════════════════════════════════════════════════════════════════════════════
% SECTION 1 — INTRODUCTION
% ═══════════════════════════════════════════════════════════════════════════════
\section{Introduction}

\subsection{Why Sensor Fusion?}

Every sensor carries its own kind of imperfection.
Wheel odometry integrates encoder tick counts into a position estimate: it is
smooth and responsive but \emph{drifts} --- small errors compound with every
revolution, so the estimated heading and position diverge from reality over
long runs.

Sensor fusion uses information from other sensors along with wheel odometry to produce an estimate that is
more accurate than either sensor alone.

\subsection{The Weighted-Sum (Complementary) Filter}

The simplest fusion method is the \textbf{complementary filter}, sometimes
called an \textit{alpha-blending} or \textit{weighted-sum} filter.
The idea is straightforward: at every timestep, nudge the odometry estimate a
little bit toward the absolute sensor reading.

\subsubsection*{Orientation Fusion}
An IMU measures  heading using a combination of sensing the Earth's magnetic field, using gyroscope measurements, and using accelerometer measurements:
it does not drift, but it can be \emph{noisy} and can be disturbed by nearby
motors, metal surfaces, and electrical cables.

Given:
\begin{itemize}
  \item $\theta_{\text{odom}}$ --- heading from wheel odometry (radians,
        unbounded --- accumulates past $2\pi$)
  \item $\theta_{\text{mag}}$ --- heading from the imu (radians,
        noisy)
  \item $\alpha \in [0, 1]$ --- the \emph{fusion weight} (IMU trust)
\end{itemize}

The fused heading update is:
\begin{equation}
  \hat{\theta}_{\text{fused}}
    = \theta_{\text{odom}}
    + \alpha \cdot \mathrm{wrap}\!\left(\theta_{\text{imu}} - \theta_{\text{odom}}\right)
  \label{eq:cf-heading}
\end{equation}

where $\mathrm{wrap}(\cdot)$ folds the angle difference into $[-\pi, +\pi]$
to avoid discontinuities at the $\pm 180^\circ$ boundary.

\begin{itemize}
  \item $\alpha = 0$: pure odometry --- no IMU correction.
  \item $\alpha = 1$: pure IMU --- fused heading snaps to the
        IMU reading every tick.
  \item Small $\alpha$ (e.g.\ $0.02$): gentle long-term drift correction.
        The IMU slowly pulls the estimate back toward truth without
        introducing moment-to-moment noise.
\end{itemize}

In code (\texttt{sensor\_fusion.py}):
\begin{lstlisting}[style=python, caption={ComplementaryFilter.update() in sensor\_fusion.py}]
def update(self, odom_theta, mag_heading, linear_vel, angular_vel):
    if mag_heading is None:
        return odom_theta          # no calibrated mag: fall back to odometry
    return odom_theta + self.alpha * _wrap(mag_heading - odom_theta)
\end{lstlisting}

\subsubsection*{Position Fusion}

The same idea applies to the $(x, y)$ position, replacing the IMU
with \emph{ArUco GPS} (described in Section~\ref{sec:gps-emulation}):
\begin{equation}
  \hat{\mathbf{p}}_{\text{fused}}
    = \mathbf{p}_{\text{odom}}
    + \alpha_{\text{pos}} \cdot \left(\mathbf{p}_{\text{GPS}} - \mathbf{p}_{\text{odom}}\right)
  \label{eq:cf-position}
\end{equation}

When GPS is unavailable (tag out of camera view), the robot
\emph{dead-reckons} from the last valid GPS fix using the odometry delta,
so position errors only accumulate \emph{since the last fix} rather than from
the beginning of the run.

\subsection{Other Fusion Strategies (for the Curious)}

\begin{itemize}
  \item \textbf{Adaptive Complementary Filter} ---
        The weight $\alpha$ decreases automatically as the robot moves faster.
        When nearly stationary the IMU is trusted more; at speed,
        odometry is more reliable short-term.

  \item \textbf{1-D Kalman Filter on Heading} ---
        A statistically optimal linear estimator. It models both
        \textit{process noise} (how much the odometry prediction can err per
        step) and \textit{measurement noise} (how noisy the IMU is).
        More principled than a fixed $\alpha$, but requires tuning two noise
        parameters instead of one.

  \item \textbf{Extended Kalman Filter (EKF)} ---
        Generalizes the Kalman filter to nonlinear systems. Standard approach
        for full 2-D/3-D pose estimation in mobile robotics; implemented in
        packages such as \texttt{robot\_localization} (ROS).
\end{itemize}

% To swap strategies in student code:
% \begin{lstlisting}[style=python, caption={Switching fusion strategy in main.py}]
% from robot.sensor_fusion import AdaptiveComplementaryFilter, HeadingKalmanFilter

% # Adaptive complementary filter (velocity-aware)
% robot.set_fusion_strategy(AdaptiveComplementaryFilter(
%     alpha_min=0.005, alpha_max=0.10))

% # Kalman filter
% robot.set_fusion_strategy(HeadingKalmanFilter(
%     process_noise=1e-4, measurement_noise=0.05))
% \end{lstlisting}

\newpage

% ═══════════════════════════════════════════════════════════════════════════════
% SECTION 2 — SYSTEM ARCHITECTURE
% ═══════════════════════════════════════════════════════════════════════════════
\section{System Architecture}

\subsection{Jetson Nano and Raspberry Pi~5 Communication}
\label{sec:jetson-rpi}

The field localization system uses a \textbf{Jetson Nano} positioned at the
side of the arena, running a RealSense D435/D455 depth camera that looks down
across the course.
Each robot's \textbf{Raspberry Pi~5} communicates with the Jetson over the
lab Wi-Fi network.

\begin{warningbox}
  The lab router performs NAT (Network Address Translation). This means
  the Jetson cannot directly initiate a connection \emph{to} the RPi. Instead,
  the \emph{RPi always initiates} the TCP connection to the Jetson on
  port~7777.  Once the socket is open, data flows in both directions and the
  NAT table entry remains alive.
\end{warningbox}

\subsubsection*{Connection Flow}

\begin{enumerate}
  \item The \texttt{robot\_gps} node starts on the RPi and opens a TCP
        connection to the Jetson at port~7777 (configurable).
  \item The Jetson accepts the connection and continuously streams
        line-delimited JSON detection messages.
  \item If the connection drops (network hiccup, container restart), the RPi
        node retries every 3~seconds automatically.
\end{enumerate}

\begin{figure}
    \centering
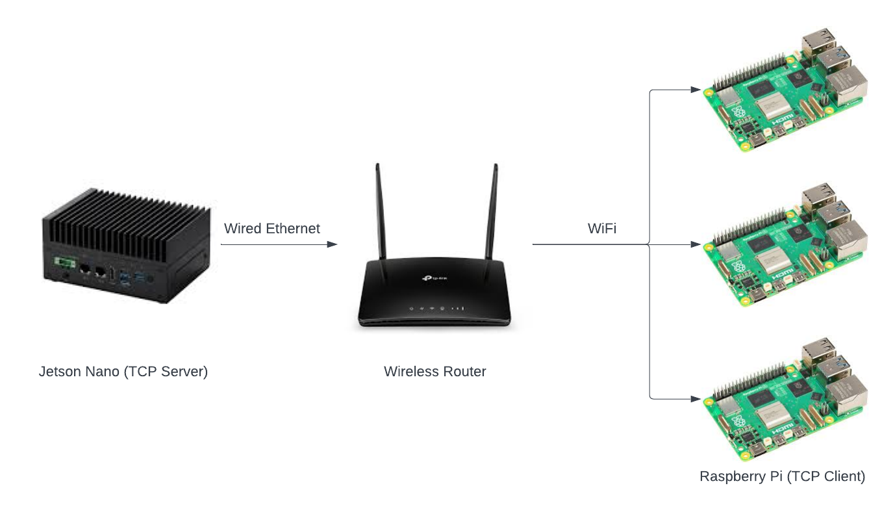
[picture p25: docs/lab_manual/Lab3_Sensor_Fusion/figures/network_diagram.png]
    
    \caption{Network diagram}
    \label{fig:placeholder}
\end{figure}

\subsection{GPS Emulation via ArUco Markers}
\label{sec:gps-emulation}

Because GPS signals are unavailable indoors, we emulate global positioning
using computer vision:

\begin{itemize}
  \item \textbf{Corner anchors (IDs 0--3):} Four ArUco markers are fixed at
        the corners of the arena. The Jetson uses these to establish a
        world-frame coordinate system, with origin $(0, 0)$ at corner~0,
        $x$ pointing toward corner~1, and $y$ pointing toward corner~2.

  \item \textbf{Rover markers (IDs 11--26):} Each robot group has one unique
        marker mounted flat and visible from above.
        The Jetson detects it, projects its position onto the ground plane via
        homography, and reports $(x, y, \theta)$ in metres.
\end{itemize}

\subsubsection*{Data Format}

Detections are sent as a single line of JSON per batch:
\begin{lstlisting}[style=json, caption={GPS message format (one line per batch)}]
{"stamp": 1712345678.0,
 "detections": [{"tag_id": 11, "x": 1.23, "y": 0.45, "theta": 1.57}]}
\end{lstlisting}

The RPi converts this into a ROS~2 \texttt{TagDetectionArray} message
(metres $\to$ mm conversion happens in \texttt{robot.py}) and publishes on
\texttt{/tag\_detections}.

\subsubsection*{GPS Offset Calibration}

The Jetson's world frame origin is at the ArUco corner markers, not at
your robot's starting position.
A fixed offset maps the Jetson's world frame to the arena coordinate frame
and is already pre-measured for the venue:

\begin{lstlisting}[style=python]
# Pre-configured in test_position_fusion.py and main.py
GPS_OFFSET_X_MM = 609.6
GPS_OFFSET_Y_MM = -304.8
\end{lstlisting}

\begin{notebox}
  \textbf{You do not need to change the GPS offset.}
  These values are pre-measured for the current venue and are already set.
\end{notebox}

\subsection{Venue and Coordinate System}
\label{sec:venue-coords}

The arena uses a fixed global coordinate frame established by the four corner
ArUco anchors (IDs~0--3):

\begin{itemize}
  \item \textbf{Origin $(0,\,0)$}: Corner anchor~0.
  \item \textbf{$x$-axis}: Points from corner~0 toward corner~1 (across the
        short dimension of the arena).
  \item \textbf{$y$-axis}: Points from corner~0 toward corner~2 (along the
        long dimension of the arena, toward the ramp).
\end{itemize}

The designated starting position is at the taped corner near anchor~0.
When the robot is placed correctly at the start, it should be
\textbf{pointing in the positive $y$ direction} --- that is, facing toward the
ramp.  This heading corresponds to $90^\circ$ in the standard counter-clockwise
convention (measured from the $x$-axis), which is why
\texttt{INITIAL\_THETA\_DEG = 90.0} in \texttt{main.py}.

\begin{figure}[H]
    \centering
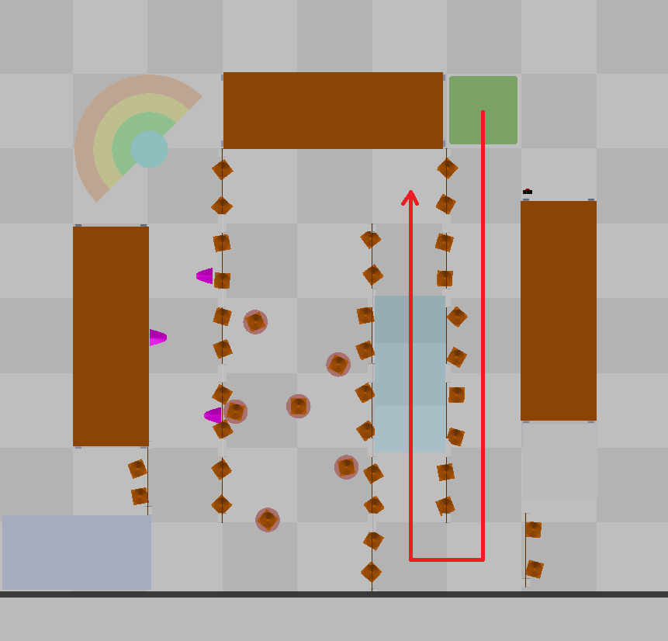
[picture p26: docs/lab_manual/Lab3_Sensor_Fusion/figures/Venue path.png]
    
    \caption{Venue layout and planned path (red). The positive $y$-axis
             points toward the ramp; the robot starts pointing in this
             direction.}
    \label{fig:venue-overview}
\end{figure}

\subsection{Sensor Fusion Integration into the Existing Code}

The fusion logic is layered transparently inside the \texttt{Robot} class so
that student code in \texttt{main.py} does not need to call any fusion
functions explicitly:

\begin{enumerate}
  \item The \texttt{bridge} node publishes raw odometry on
        \texttt{/sensor\_kinematics} (25~Hz) and IMU data on
        \texttt{/sensor\_imu} (25~Hz).
  \item \texttt{robot.py} subscribes to both, plus \texttt{/tag\_detections}.
  \item On every \texttt{/sensor\_kinematics} callback, it:
    \begin{enumerate}[label=\alph*.]
      \item Incrementally unwraps the IMU heading to avoid
            $\pm 180^\circ$ discontinuities.
      \item Calls the active fusion strategy (Eq.~\ref{eq:cf-heading}).
      \item Applies the position complementary filter (Eq.~\ref{eq:cf-position}).
    \end{enumerate}
  \item \texttt{robot.get\_pose()} and \texttt{robot.get\_fused\_orientation()}
        return the fused values now.
\end{enumerate}

% \begin{notebox}
%   All sensor data is protected by a thread lock. The ROS spin thread and
%   your FSM in \texttt{main.py} run on separate threads; the \texttt{Robot}
%   API handles synchronisation transparently.
% \end{notebox}

\subsection{Changes to the Existing ROS~2 Architecture}

Table~\ref{tab:topics} summarises the topic-level changes relative to the
baseline \texttt{main} branch.

\begin{table}[H]
  \centering
  \caption{New and modified ROS~2 topics}
  \label{tab:topics}
  \begin{tabularx}{\textwidth}{llX}
    \toprule
    \textbf{Topic} & \textbf{Status} & \textbf{Description} \\
    \midrule
    \texttt{/sensor\_imu} & Pre-existing & IMU data at 25~Hz (quaternion,
        raw accel/gyro, magnetometer). Published by bridge node. \\
    \texttt{/sensor\_kinematics} & Pre-existing & Raw odometry $(x, y,
        \theta, v_x, v_y, \omega)$ at 25~Hz. \\
    \texttt{/tag\_detections} & \textbf{New} & ArUco GPS positions
        (metres, world frame). Published by \texttt{robot\_gps} node. \\
    % \texttt{/fused\_kinematics} & \textbf{New} & Fused pose
    %     $(x_{\text{fused}}, y_{\text{fused}}, \theta_{\text{fused}})$
    %     at 25~Hz. Published by robot node. \\
    \bottomrule
  \end{tabularx}
\end{table}

\begin{table}[H]
  \centering
  \caption{New and modified ROS~2 nodes}
  \label{tab:nodes}
  \begin{tabularx}{\textwidth}{llX}
    \toprule
    \textbf{Node} & \textbf{Package} & \textbf{Description} \\
    \midrule
    \texttt{robot} & \texttt{robot} & Main robot FSM; now subscribes to
        \texttt{/sensor\_imu} and \texttt{/tag\_detections}; publishes
        \texttt{/fused\_kinematics}. \\
    \texttt{robot\_gps} & \texttt{sensors} & \textbf{New.} TCP client that
        connects to Jetson and re-publishes ArUco detections as
        \texttt{TagDetectionArray}. \\
    \texttt{bridge} & \texttt{bridge} & Unchanged (UART $\leftrightarrow$
        ROS bridge). \\
    \bottomrule
  \end{tabularx}
\end{table}

\begin{figure}[H]
\centering
\begin{tikzpicture}[
  rosnode/.style={
    draw, rectangle, rounded corners=3pt,
    fill=blue!18, minimum width=2.2cm, minimum height=0.65cm,
    font=\ttfamily\small, text centered
  },
  rostopic/.style={
    draw, ellipse,
    fill=orange!25, minimum width=2.8cm, minimum height=0.6cm,
    font=\ttfamily\footnotesize, text centered
  },
  arr/.style={-{Stealth[length=6pt]}, thick},
]

%% ── ROS nodes ────────────────────────────────────────────────────────────────
\node[rosnode] (bridge)    at (0,    1.5)  {bridge};
\node[rosnode] (robot_gps) at (0,   -1.5)  {robot\_gps};
\node[rosnode] (robot)     at (7.5,  0)    {robot};

%% ── Topics ───────────────────────────────────────────────────────────────────
\node[rostopic] (imu)     at (3.8,  2.6)  {/sensor\_imu};
\node[rostopic] (kin)     at (3.8,  0.4)  {/sensor\_kinematics};
\node[rostopic] (tag)     at (3.8, -1.5)  {/tag\_detections};
% \node[rostopic] (fused)   at (11.0,  0)   {/fused\_kinematics};

%% ── Edges ───────────────────────────────────────────────────────────────────
\draw[arr] (bridge)    -- (imu);
\draw[arr] (bridge)    -- (kin);
\draw[arr] (imu)       -- (robot);
\draw[arr] (kin)       -- (robot);
\draw[arr] (robot_gps) -- (tag);
\draw[arr] (tag)       -- (robot);
% \draw[arr] (robot)     -- (fused)

\end{tikzpicture}

\smallskip
{\footnotesize
  \tikz\node[draw,rectangle,rounded corners=2pt,fill=blue!18,minimum width=0.9cm,minimum height=0.45cm,font=\ttfamily\tiny]{node};\;ROS\,2 node\quad
  \tikz\node[draw,ellipse,fill=orange!25,minimum width=0.9cm,minimum height=0.45cm,font=\ttfamily\tiny]{topic};\;topic
}
\caption*{\textbf{Figure:} ROS\,2 node graph for sensor fusion.}
\end{figure}

% 
\newpage

% ═══════════════════════════════════════════════════════════════════════════════
% SECTION 3 — SETUP
% ═══════════════════════════════════════════════════════════════════════════════
\section{Setup}

\subsection{List of Changed Files}

Table~\ref{tab:files} lists every file that differs between the baseline
\texttt{main} branch and the sensor-fusion branch.
Pull these changes from upstream before beginning (Section~\ref{sec:fetch}).
\begin{table}[H]
  \centering\small
  \caption{Files changed relative to baseline \texttt{main} branch}
  \label{tab:files}
  \begin{tabularx}{\textwidth}{%
    >{\ttfamily\raggedright\arraybackslash}p{0.48\textwidth}  % file path — wraps
    l                                                          % change badge
    X}                                                         % notes — fills remainder
    \toprule
    \normalfont\textbf{File} & \textbf{Change} & \textbf{Notes} \\
    \midrule
    firmware/arduino/src/config.h
      & Modified & Set \texttt{IMU\_ENABLED~1} \\[2pt]
    ros2\_ws/src/robot/robot/sensor\_fusion.py
      & \textbf{New} & OrientationComplementaryFilter, PositionComplementaryFilter \\[2pt]
    ros2\_ws/src/robot/robot/robot.py
      & Modified & IMU/GPS subscription callbacks, fusion logic,
        \texttt{/fused\_kinematics} publisher \\[2pt]
    ros2\_ws/src/robot/robot/main.py
      & Modified & Pure-pursuit path planner integration, student task
        scaffolding \\[2pt]
    ros2\_ws/src/robot/robot/\\test\_orientation\_fusion.py
      & \textbf{New} & Orientation fusion test harness \\[2pt]
    ros2\_ws/src/robot/robot/\\test\_position\_fusion.py
      & \textbf{New} & Position fusion test harness \\[2pt]
    ros2\_ws/src/robot/launch/\\test\_orientation\_fusion.launch.py
      & \textbf{New} & Launch file for orientation test \\[2pt]
    ros2\_ws/src/robot/launch/\\test\_position\_fusion.launch.py
      & \textbf{New} & Launch file for position test \\[2pt]
    ros2\_ws/src/sensors/sensors/\\robot\_gps\_node.py
      & \textbf{New} & TCP bridge to Jetson ArUco detector \\[2pt]
    ros2\_ws/src/robot/launch/robot.launch.py
      & Modified & Adds \texttt{robot\_gps} node to launch graph \\
    \bottomrule
  \end{tabularx}
\end{table}

\subsection{Fetching from Upstream/Main}
\label{sec:fetch}

Run the following commands to pull the
latest changes:

\begin{lstlisting}[style=bash, caption={Fetching and building the sensor fusion branch}]
# Inside the Project-NUEVO/ directory

# Pull latest changes from the main branch
git fetch upstream
git rebase upstream/main

\end{lstlisting}

\begin{notebox}
  If you have local changes in \texttt{main.py}, Git may report a merge
  conflict. Resolve conflicts manually in your editor, then run
  \texttt{git add} and \texttt{git merge --continue}.
\end{notebox}

\subsection{Enabling the IMU in the Arduino Firmware}

By default, the IMU is disabled in the firmware to save boot time on robots
that have no sensor attached.
You must enable it, recompile, and re-upload.

\begin{enumerate}
  \item Open \texttt{firmware/arduino/src/config.h} and find the line:
\begin{lstlisting}[style=cpp]
#define IMU_ENABLED   0
\end{lstlisting}
        Change it to:
\begin{lstlisting}[style=cpp]
#define IMU_ENABLED   1
\end{lstlisting}

  \item Recompile and upload according to Week 1 instructions for flashing Arduino firmware

  \item Verify: the bridge log should print IMU telemetry lines at 25~Hz
        once the firmware enters \texttt{RUNNING} state.
\end{enumerate}

\subsection{Connecting the IMU}

The ICM-20948 communicates over the I\textsuperscript{2}C bus.
Connect the breakout board to the Arduino Mega using the provided
I\textsuperscript{2}C wire assembly.

\begin{warningbox}
  Power down the robot completely before making or changing any wiring
  connections. Connecting the IMU to a live board can damage both the
  Arduino and the sensor.
\end{warningbox}

% \begin{table}[H]
%   \centering
%   \caption{IMU wiring to Arduino Mega 2560}
%   \label{tab:wiring}
%   \begin{tabular}{lll}
%     \toprule
%     \textbf{IMU Pin} & \textbf{Arduino Pin} & \textbf{Notes} \\
%     \midrule
%     VCC & 3.3V & Do \emph{not} connect to 5~V --- sensor is 3.3~V logic \\
%     GND & GND & Any GND pin \\
%     SDA & Pin 20 (SDA) & Hardware I\textsuperscript{2}C bus \\
%     SCL & Pin 21 (SCL) & Hardware I\textsuperscript{2}C bus \\
%     AD0 & 3.3V & Sets I\textsuperscript{2}C address to 0x69 \\
%     \bottomrule
%   \end{tabular}
% \end{table}

% \diagramplaceholder[4cm]{IMU wiring diagram: SparkFun ICM-20948 breakout $\to$ Arduino Mega 2560. Show 4-wire connection with colour coding (red=VCC, black=GND, blue=SDA, yellow=SCL) and the AD0 pull-up.}

% \begin{notebox}
%   The SparkFun ICM-20948 breakout has AD0 high by default (connected
%   internally to 3.3~V via a pull-up resistor), giving I\textsuperscript{2}C
%   address \texttt{0x69}.  This matches \texttt{IMU\_AD0\_VAL~1} in
%   \texttt{config.h} --- no change needed.
% \end{notebox}

\subsection{IMU Calibration}

The IMU must be calibrated before any fusion test will work
correctly.

\begin{enumerate}
  \item Start the Docker stack and bring the bridge up:
\begin{lstlisting}[style=bash]
docker compose -f ros2_ws/docker/docker-compose.rpi.yml up -d
source ros2_ws/docker/enter_ros2.sh rpi
ros2 run bridge bridge
\end{lstlisting}
  \item In the NUEVO front end UI, you should see the IMU show up. Calibration can be performed from there.
\end{enumerate}

\subsection{Mounting the ArUco Tag}

\begin{enumerate}
  \item Attach your printed ArUco tag to the top flat surface of the robot
        so it is clearly visible from directly above.
  \item Keep the tag level with respect to the floor --- tilt causes measurement error.
  \item \textbf{Align the tag with the robot axes:} mount the tag so that
        the sides of the printed square are parallel to the robot's forward
        and sideways axes.  Rotation of the tag relative to the robot body
        introduces a systematic heading error in the camera-derived pose.
  \item \textbf{Center the tag on the drive-axle line:} the localization
        system reports the tag's position in the world frame; it then
        subtracts a body-frame offset to recover the robot's wheel-center
        position.  If your tag is not directly above the midpoint of the
        line connecting the two drive wheels, measure the offset and set
        the following constants in \texttt{robot.py}:
\begin{lstlisting}[style=python, caption={Tag body-frame offset in robot.py}]
TAG_X_OFFSET_MM = 0.0  # forward offset of tag from wheel-axle centre (mm)
TAG_Y_OFFSET_MM = 0.0  # sideways offset of tag from wheel-axle centre (mm)
\end{lstlisting}
        Positive $x$ is forward, positive $y$ is to the left.
        If the tag is centred on the axle midpoint (recommended), leave
        both values at \texttt{0.0}.
  \item Make sure the tag ID matches the one assigned to your group
        (printed on the tag envelope).
\end{enumerate}

\begin{figure}
    \centering
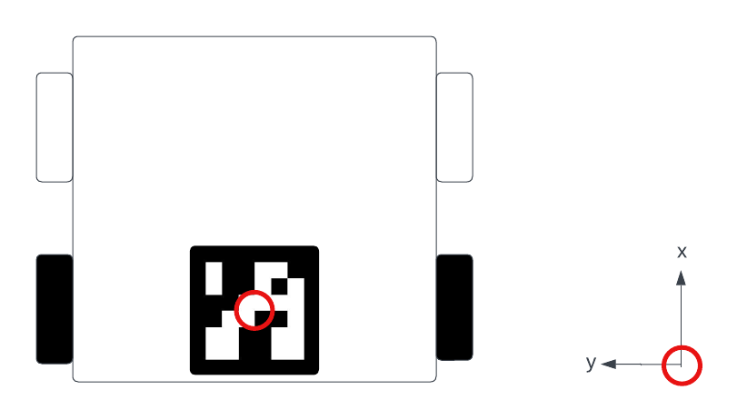
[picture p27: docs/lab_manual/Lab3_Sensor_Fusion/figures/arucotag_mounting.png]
    
    \caption{ArUco tag mounting}
    \label{fig:aruco-mounting}
\end{figure}

% \begin{notebox}
%   Perform calibration on the actual arena surface, away from large metal
%   objects and power cables.  Moving the robot to a different location after
%   calibration may change the ambient field slightly, but the saved offsets
%   are a good starting point.
% \end{notebox}

\newpage

% ═══════════════════════════════════════════════════════════════════════════════
% SECTION 4 — TASKS
% ═══════════════════════════════════════════════════════════════════════════════
\section{Tasks}

% ──────────────────────────────────────────────────────────────────────────────

\subsection{Task 1: Sensor Fusion Tuning}

\begin{taskbox}{Task 1 Overview}
  Drive the robot through preprogrammed manoeuvres while varying the
  fusion weight $\alpha$.  Observe how $\alpha$ affects the trade-off between
  odometry smoothness and absolute accuracy, then choose a good value to carry
  forward into Task~2.
\end{taskbox}

% ─── Sub-task 1a ──────────────────────────────────────────────────────────────
\subsubsection{Sub-task 1a: Orientation Fusion}

\textbf{Setup:} Take the robot to an open area of the lab floor.

\textbf{Procedure:}
\begin{enumerate}
  \item Navigate to your \texttt{Project\_NUEVO} directory and start the docker container
\begin{lstlisting} [style=bash]
COMPOSE=ros2_ws/docker/docker-compose.rpi.yml
docker compose -f $COMPOSE build
docker compose -f $COMPOSE up -d
\end{lstlisting}
  \item In one terminal, go into the docker container and
        start the bridge:
\begin{lstlisting}[style=bash]
source ros2_ws\docker\enter_ros2.sh rpi
ros2 run bridge bridge
\end{lstlisting}
  \item Open \texttt{ros2\_ws/src/robot/robot/test\_orientation\_fusion.py}
        and set the fusion weight (FUSION\_ALPHA) at the top of the file:
\begin{lstlisting}[style=python, caption={Tunable parameters in test\_orientation\_fusion.py}]
FUSION_ALPHA      = 0.02    # <-- edit this value (0.0 to 1.0)
\end{lstlisting}
  \item In a \textbf{second terminal} launch the test:
\begin{lstlisting}[style=bash]
source ros2_ws/docker/enter_ros2.sh rpi
ros2 launch robot test_orientation_fusion.launch.py
\end{lstlisting}
        The robot will make a $180^\circ$ turn.
  \item After the test finishes, copy the result image to the host and view
        it in VS~Code.  Run the following \textbf{outside Docker} in a
        VS~Code terminal:
\begin{lstlisting} [style=bash]
docker cp docker-ros2_runtime-1:/root/orientation_fusion_test_result.png \
    ~/Project-NUEVO/
\end{lstlisting}
        Then navigate to \texttt{\textasciitilde/Project-NUEVO} in the
        VS~Code file explorer and \textbf{Ctrl-click} the image file to
        open it.
  \item The plot has three panels:
        \begin{itemize}
          \item \textbf{Panel 1:} Robot trajectory coloured by the magnitude of
                the fusion correction $|\hat\theta_{\text{fused}} - \theta_{\text{odom}}|$.
          \item \textbf{Panel 2:} Odometry heading vs.\ fused heading over
                time.
          \item \textbf{Panel 3:} Per-sample fusion correction
                $\hat\theta_{\text{fused}} - \theta_{\text{odom}}$ over time.
        \end{itemize}
  \item Repeat with at least three different values of \texttt{FUSION\_ALPHA}
        (e.g.\ $0.0$, $0.02$, $0.5$, $1.0$).
\end{enumerate}

% \textbf{Questions to explore:}
% \begin{itemize}
%   \item At $\alpha = 0$, do the two heading traces match?
%         What does this tell you?
%   \item At $\alpha = 1$, how noisy does the fused heading become?
%   \item At what value of $\alpha$ does the fused heading stay smooth while
%         still correcting the odometry drift after two laps?
%   \item Is the correction larger at the beginning or end of each lap?  Why?
% \end{itemize}

\begin{notebox}
  Record the $\alpha$ value you choose that gives you the best results. You will need it in Task~2 when you
  configure \texttt{main.py}.
\end{notebox}

\begin{warningbox}
  \textbf{Orientation fusion is disabled in the actual robot run
  (\texttt{ORIENTATION\_ALPHA = 0.0} in \texttt{robot.py}).}
  The IMU magnetometer does not operate accurately in the presence of the
  strong magnetic fields in
  the current room.  Setting \texttt{ORIENTATION\_ALPHA = 0} means the robot
  relies on pure wheel odometry for heading, avoiding IMU-induced errors.
  Task~1a is a learning exercise to understand the complementary filter
  trade-offs; you should \emph{not} set \texttt{ORIENTATION\_ALPHA > 0} in
  \texttt{main.py} for the actual course run.
\end{warningbox}

\begin{notebox}
  \textbf{IMU mounting orientation (\texttt{IMU\_Z\_DOWN} in
  \texttt{robot.py}):} If the IMU board is mounted with its $z$-axis pointing
  downward (chip face down), set \texttt{IMU\_Z\_DOWN = True} so the yaw sign
  is corrected in software.  In our current setup the chip faces upward, so
  the default \texttt{IMU\_Z\_DOWN = False} is correct.  This parameter is
  academic given that orientation fusion is disabled, but you are welcome to
  experiment with it.
\end{notebox}

% ─── Sub-task 1b ──────────────────────────────────────────────────────────────
\subsubsection{Sub-task 1b: Position Fusion}

\textbf{Setup:}
\begin{enumerate}
  \item Place the robot at the designated starting position
        (marked by tape on the arena floor, along the ramp approach).
        The starting corner of the robot chassis should align with the tape
        marks.  The robot must be \textbf{facing the positive $y$ direction}
        (toward the ramp) --- see Section~\ref{sec:venue-coords} for the
        coordinate system.
  \item Ensure the Jetson Nano is running and its camera can see your ArUco
        tag from above.
\end{enumerate}

\textbf{Tunable Parameter:}

The GPS fusion weight \texttt{POSITION\_ALPHA} controls how aggressively the
fused position is pulled toward the GPS reading each timestep.
It is defined as a class constant in \texttt{robot.py}:
\begin{lstlisting}[style=python, caption={POSITION\_ALPHA in robot.py}]
POSITION_ALPHA = 0.10  # GPS weight for position fusion (0.0 to 1.0)
\end{lstlisting}
Increase this value to trust GPS more; decrease it to rely more on odometry.
You will tune this by observing how the robot tracks the straight-line path
during the test.

\textbf{Procedure:}
\begin{enumerate}
  \item If not already running, start the bridge in one terminal inside the
        container:
\begin{lstlisting}[style=bash]
docker compose -f ros2_ws/docker/docker-compose.rpi.yml up -d
source ros2_ws/docker/enter_ros2.sh rpi
ros2 run bridge bridge
\end{lstlisting}
  \item In a \textbf{second terminal} inside the container, launch the test:
\begin{lstlisting}[style=bash]
source ros2_ws/docker/enter_ros2.sh rpi
ros2 launch robot test_position_fusion.launch.py
\end{lstlisting}
        The robot drives straight forward for 1000~mm.
  \item The result plot is saved directly to \texttt{\textasciitilde/Project-NUEVO/}
        on the host --- no \texttt{docker cp} needed.
        In a VS~Code terminal navigate to \texttt{\textasciitilde/Project-NUEVO}
        and \textbf{Ctrl-click}
        \texttt{position\_fusion\_test\_result.png} to open it.
        The plot shows four panels: X over time, Y over time, 2-D trajectory,
        and position error magnitude (GPS-active periods shaded green).
  \item Repeat with \texttt{POSITION\_ALPHA} = $0.0$, $0.5$, $1.0$ (edit the
        value in \texttt{robot.py} and relaunch each time).
        Also try temporarily removing your tag for a
        few seconds mid-run to observe dead-reckoning behaviour.
\end{enumerate}

% \textbf{Questions to explore:}
% \begin{itemize}
%   \item During GPS-active periods, how does the fused path differ from
%         the raw odometry path?
%   \item When you block the tag, what happens to the fused position?
%         Does it freeze, jump, or follow odometry?
%   \item What happens to position error right after GPS comes back online?
%   \item Why is $\alpha = 1.0$ (snap entirely to GPS each tick) probably
%         \emph{not} a good choice, even though GPS is more accurate?
% \end{itemize}

% ──────────────────────────────────────────────────────────────────────────────
\subsection{Task 2: Obstacle Course Navigation}

\begin{taskbox}{Task 2 Overview}
  Modify \texttt{main.py} to give the robot a set of waypoints that navigate
  through the full obstacle course. The robot must use the fused pose
  (heading $+$ position) from Task~1 to stay on path.
\end{taskbox}

\subsubsection{Course Description}

The course is set up on the arena floor (see Figure~\ref{fig:venue-overview}
in Section~\ref{sec:venue-coords}). Key features:
\begin{itemize}
  \item \textbf{Start:} Predefined corner, robot placed against tape markers.
  \item \textbf{Ramp:} The robot must drive over the ramp (note: position sensor fusion is useful here)
  \item \textbf{Finish:} End within the tile boundaries
\end{itemize}

\subsubsection{Modifying \texttt{main.py}}

Open \texttt{ros2\_ws/src/robot/robot/main.py}.

\begin{notebox}
  \textbf{Starting heading (\texttt{INITIAL\_THETA\_DEG}):}
  The top of \texttt{main.py} sets
\begin{lstlisting}[style=python]
INITIAL_THETA_DEG = 90.0
\end{lstlisting}sudo debugfs /dev/mmcblk0p2

  This tells the odometry system that the robot starts pointing at $90^\circ$,
  which corresponds to the positive $y$ direction in the arena frame (toward
  the ramp) --- see Section~\ref{sec:venue-coords}.sudo debugfs /dev/mmcblk0p2

  \textbf{You do not need to change this value} provided you place the robot at
  the taped starting position with the robot pointing forward (toward the ramp).
\end{notebox}

In the \texttt{INIT} block, replace the placeholder waypoints with the course waypoints.
All coordinates are in \textbf{millimetres}, in the arena frame
(origin at start corner, $x$ across, $y$ toward the ramp).

\begin{lstlisting}[style=python, caption={Obstacle course waypoints in main.py (fill in from the course diagram)}]
path_control_points = [
    # (x_mm, y_mm)
    (   0.0,     0.0),   # Start
    (   0.0,   ???.?),   # Waypoint 1 -- fill in from diagram
    ( ???.0,   ???.0),   # Waypoint 2
    # ... add remaining waypoints ...
    (   0.0,     0.0),   # Return to start
]
\end{lstlisting}

\begin{notebox}
  Use the \texttt{POSITION\_ALPHA} value you found in Task~1b.
  Edit the constant directly in \texttt{robot.py} before launching, or
  override it at runtime via \texttt{robot.set\_pos\_fusion\_alpha()} at the
  top of \texttt{run()} in \texttt{main.py}:
\begin{lstlisting}[style=python]
def run(robot: Robot) -> None:
    configure_robot(robot)
    # ORIENTATION_ALPHA stays 0.0 (set in robot.py) -- do not override
    robot.set_pos_fusion_alpha(0.10)   # position fusion weight from Task 1b
    # ... rest of run() ...
\end{lstlisting}
\end{notebox}

\subsubsection{Running the Course}

\begin{enumerate}
  \item Place the robot at the taped start position.
  \item In one terminal inside the Docker container, start the bridge:
\begin{lstlisting}[style=bash]
docker compose -f ros2_ws/docker/docker-compose.rpi.yml up -d
source ros2_ws/docker/enter_ros2.sh rpi
ros2 run bridge bridge
\end{lstlisting}
  \item In a \textbf{second terminal} inside the container, launch the full
        robot stack:
\begin{lstlisting}[style=bash]
source ros2_ws/docker/enter_ros2.sh rpi
ros2 launch robot robot.launch.py
\end{lstlisting}
  \item Verify that the bridge is connected and the firmware is in
        \texttt{IDLE} state (orange LED on).
  \item Press \textbf{BTN\_1} on the robot to enter \texttt{MOVING} state
        (green LED on).
  \item Monitor the console output for pose and pursuit-point debug prints.
  \item If the robot deviates significantly, stop it with Ctrl-C, adjust
        waypoints or fusion weights, and relaunch.
  \item After the run, press \textbf{BTN\_2} to stop the robot processes and copy the trajectory plot to the host and view it in
        VS~Code.  Run the following \textbf{outside Docker} in a VS~Code
        terminal:
\begin{lstlisting}[style=bash]
docker cp docker-ros2_runtime-1:/ros2_ws/trajectory.png ~/Project-NUEVO/
\end{lstlisting}
        Then navigate to \texttt{\textasciitilde/Project-NUEVO} in the
        VS~Code file explorer and \textbf{Ctrl-click} \texttt{trajectory.png}
        to open it.
\end{enumerate}

\newpage

% ═══════════════════════════════════════════════════════════════════════════════
% SECTION 5 — DELIVERABLE
% ═══════════════════════════════════════════════════════════════════════════════
\section{Deliverable}

\begin{taskbox}{Lab Deliverable}
  Demonstrate your robot completing the full obstacle course \emph{without
  any manual intervention} (no pushing, nudging, or repositioning once
  \texttt{BTN\_1} is pressed).
\end{taskbox}

The demonstration must satisfy all of the following criteria:

\begin{enumerate}
  \item The robot starts from the designated starting position.
  \item It navigates over the ramp.
  \item It passes through all designated waypoints in order.
  \item It finishes within the tile boundaries.
  \item Sensor fusion (both orientation and position) must be active
        (i.e.\ \texttt{FUSION\_ALPHA~>~0} and \texttt{POS\_FUSION\_ALPHA~>~0}).
\end{enumerate}

% \textbf{Grading Notes:}
% \begin{itemize}
%   \item A run that completes the course with the robot touching a pylon
%         (but not knocking it over) will receive partial credit.
%   \item You may run the course as many times as needed during the demo
%         period.
%   \item Be prepared to show the console output and explain your choice
%         of $\alpha$ values.
% \end{itemize}

\newpage

% ═══════════════════════════════════════════════════════════════════════════════
% APPENDIX
% ═══════════════════════════════════════════════════════════════════════════════
\appendix
\section{Quick-Reference: Robot API Methods Used in This Lab}

\begin{tabularx}{\textwidth}{lX}
  \toprule
  \textbf{Method} & \textbf{Description} \\
  \midrule
  \texttt{robot.get\_pose()} &
    Returns \texttt{(x, y, theta\_deg)} in the configured unit (mm by
    default). Uses fused position and odometry heading.\\[4pt]
  \texttt{robot.get\_fused\_orientation()} &
    Returns the fused heading in degrees (IMU-corrected). \\[4pt]
  \texttt{robot.set\_velocity(lin, ang\_deg\_s)} &
    Commands linear velocity (mm/s) and angular velocity (deg/s). \\[4pt]
  \texttt{robot.stop()} &
    Sends a zero-velocity command immediately. \\[4pt]
  \texttt{robot.set\_fusion\_alpha(alpha)} &
    Sets the heading complementary-filter weight (0--1). \\[4pt]
  \texttt{robot.set\_pos\_fusion\_alpha(alpha)} &
    Sets the position complementary-filter weight (0--1). \\[4pt]
  \texttt{robot.set\_gps\_offset(x\_mm, y\_mm)} &
    Sets the GPS world-frame to arena-frame offset. \\[4pt]
  \texttt{robot.is\_gps\_active()} &
    Returns \texttt{True} if a GPS fix was received within the last 1~s. \\[4pt]
  \texttt{robot.reset\_odometry()} &
    Resets the firmware odometry to the initial heading. \\
  \bottomrule
\end{tabularx}

\section{Troubleshooting}

\begin{tabularx}{\textwidth}{lX}
  \toprule
  \textbf{Symptom} & \textbf{Fix} \\
  \midrule
  IMU data not appearing in bridge log &
    Check \texttt{IMU\_ENABLED 1} in \texttt{config.h} and re-upload.
    Verify SDA/SCL wiring with a multimeter. \\[4pt]
  \texttt{/tag\_detections} topic empty &
    Ensure \texttt{robot\_gps} node is running. Check that the Jetson
    Docker container is up and the tag is visible to the camera. \\[4pt]
  IMU magnetometer always shows \texttt{calibrated: false} &
    Redo calibration. \\[4pt]
  Robot spins in place or drives erratically &
    Check that \texttt{LEFT\_WHEEL\_DIR\_INVERTED} and
    \texttt{RIGHT\_WHEEL\_DIR\_INVERTED} match your physical wiring.
    Run \texttt{ros2 echo /sensor\_kinematics} to inspect odometry. \\[4pt]
  GPS position jumps discontinuously &
    Set \texttt{POS\_FUSION\_ALPHA} to a smaller value (e.g.\ 0.3) so GPS
    corrections are applied gradually. \\[4pt]
  Fused heading drifts even with IMU active &
    Increase \texttt{FUSION\_ALPHA} slightly. Verify calibration was
    performed on the arena. \\
  \bottomrule
\end{tabularx}

\end{document}

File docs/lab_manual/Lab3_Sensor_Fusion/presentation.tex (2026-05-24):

\documentclass{beamer}
\usepackage{tikz}
\usepackage{amsmath}
\usetikzlibrary{shapes.geometric, arrows, positioning}
\usepackage{textcomp} % Required for the upquote option
\usepackage{listings}
\lstset{
    basicstyle=\ttfamily,
    columns=fullflexible,
    keepspaces=true,
    upquote=true
}

\title{Sensor Fusion: Integrating IMU and ArUco-Based GPS}
\subtitle{MAE 162E Capstone}
\author{Jimmy Yang, Po-Chih (Toby) Chen, Ting-Hao (Jason) Liu, Shuo-Wu (Will) Shih}
\date{April 15, 2026}

\begin{document}

\frame{\titlepage}

\begin{frame}{Background and Motivation}
    \textbf{Goal:} Determine the precise pose (position and orientation) of the robot for planning and navigation through the obstacle course.
    \vspace{0.5cm}
    \begin{itemize}
        \item \textbf{Current Stage:} The robot is able to navigate through a series of waypoints using dead reckoning (pose estimation from wheel odometry), but the accumulated drift causes it to deviate from the intended path over time.
        \item \textbf{The Problem:} Wheel slippage and encoder quantization cause accumulated drift over time.
        \item \textbf{The Solution:} Sensor fusion combines high-frequency odometry with absolute external sensors to produce an optimal estimate.
    \end{itemize}
\end{frame}

\begin{frame}{Sensor Modalities and Limitations}
    \begin{itemize}
        \item \textbf{Wheel Odometry (100 Hz)}
        \begin{itemize}
            \item \textit{Measurement:} Pose $\mathbf{p}_{\text{odom}}, \theta_{\text{odom}}$ from wheel encoders using differential drive kinematics.
            \item \textit{Advantage:} High update rate gives smooth local trajectory however subject to unbounded drift over long distances.
        \end{itemize}
        \item \textbf{Inertial Measurement Unit (IMU) (25 Hz)}
        \begin{itemize}
            \item \textit{Advantage:} Absolute heading reference via magnetometer and gravity vector.
            \item \textit{Limitation:} Lower update rate, subject to noise and magnetic interference from motors/cables.
        \end{itemize}
        \item \textbf{ArUco-Based GPS (10 Hz)}
        \begin{itemize}
            \item \textit{Advantage:} Absolute position $\mathbf{p}_{\text{GPS}}$  in the arena frame (offset to produce position in the global frame).
            \item \textit{Limitation:} Lower update rate, subject to camera occlusion and latency.
        \end{itemize}
    \end{itemize}
\end{frame}

\begin{frame}{The Complementary Filter}
    A weighted-sum filter nudges the smooth odometry estimate toward the absolute sensor reading at every timestep.
    \vspace{0.5cm}
    
    \textbf{Orientation Fusion:}
    \begin{equation*}
        \hat{\theta}_{\text{fused}} = \theta_{\text{odom}} + \alpha_{\text{orientation}} \cdot \text{wrap}(\theta_{\text{imu}} - \theta_{\text{odom}})
    \end{equation*}
    \textit{Note: \texttt{wrap()} folds the angle difference into $[-\pi, +\pi]$ to prevent discontinuities.}
    
    \vspace{0.5cm}
    \textbf{Position Fusion:}
    \begin{equation*}
        \hat{\mathbf{p}}_{\text{fused}} = \mathbf{p}_{\text{odom}} + \alpha_{\text{position}} \cdot (\mathbf{p}_{\text{GPS}} - \mathbf{p}_{\text{odom}})
    \end{equation*}
\end{frame}

\begin{frame}{Filter Tuning Parameters}
    The tuning parameters ($\alpha_{\text{orientation}}$ and $\alpha_{\text{pos}}$) determine the trust ratio between sensors, defined on the interval $[0,1]$.

    \vspace{0.3cm}
    \begin{itemize}
        \item \textbf{$\alpha = 0$:} Pure odometry (no external correction).
        \item \textbf{$\alpha = 1$:} Pure absolute sensor (snaps to reading every tick, noisy and slow update rate).
        \item \textbf{Small $\alpha$ (e.g., 0.02):} Gentle long-term drift correction. The absolute sensor slowly pulls the estimate toward the truth without introducing moment-to-moment control noise.
    \end{itemize}

    \vspace{0.3cm}
    \textbf{Note:} \texttt{ORIENTATION\_ALPHA = 0.0} in \texttt{robot.py} for the actual robot run --- the IMU magnetometer is disrupted by motor magnetic fields in the current lab.  Task~1a is a learning exercise only; do not enable orientation fusion for the course run.
\end{frame}

\begin{frame}{ROS 2 Software Architecture}
    \centering
    \resizebox{0.9\linewidth}{!}{%
    \begin{tikzpicture}[
        node distance=1.5cm and 2cm,
        box/.style={rectangle, draw, fill=blue!20, minimum width=2cm, minimum height=0.8cm, text centered, font=\small},
        topic/.style={ellipse, draw, fill=orange!20, minimum width=2.5cm, minimum height=0.8cm, text centered, font=\small},
        arrow/.style={thick,->,>=stealth}
    ]
        % Left Column (Publishers)
        \node[box] (bridge) {\texttt{bridge}};
        \node[box, below=2cm of bridge] (robotgps) {\texttt{robot\_gps}};
        
        % Middle Column (Topics)
        \node[topic, right=1.5cm of bridge, yshift=1cm] (imu) {\texttt{/sensor\_imu}};
        \node[topic, right=1.5cm of bridge, yshift=-1cm] (kinematics) {\texttt{/sensor\_kinematics}};
        \node[topic, right=1.5cm of robotgps] (tag) {\texttt{/tag\_detections}};
        
        % Right Column (Subscribers)
        % Anchoring 'robot' to the right of 'kinematics' guarantees no overlap
        \node[box, right=2.5cm of kinematics] (robot) {\texttt{robot}};
        
        % Edges
        \draw[arrow] (bridge) -- (imu);
        \draw[arrow] (bridge) -- (kinematics);
        \draw[arrow] (robotgps) -- (tag);
        
        \draw[arrow] (imu) -- (robot);
        \draw[arrow] (kinematics) -- (robot);
        \draw[arrow] (tag) -- (robot);
        
    \end{tikzpicture}%
    }
    
    \vspace{0.4cm}
    \begin{itemize}
        \item \textbf{\texttt{/sensor\_kinematics}:} Wheel odometry at 25 Hz from the Arduino.
        \item \textbf{\texttt{/sensor\_imu}:} IMU orientation data from the Arduino.
        \item \textbf{\texttt{/tag\_detections}:} Location of tags from the ArUco GPS detections.
    \end{itemize}
\end{frame}

\begin{frame}{Coordinate Frames \& GPS Alignment}
    \begin{itemize}
        \item \textbf{World/Arena Frame:} Origin $(0,0)$ at corner anchor~0; $x$-axis toward corner~1; $y$-axis toward corner~2 (toward the wall).
        \item \textbf{Starting orientation:} Robot must face the positive $y$ direction (towards the wall) $\Rightarrow$ \texttt{INITIAL\_THETA\_DEG = 90.0} in \texttt{main.py}.  No change needed if placed correctly at the taped start.
        \item \textbf{GPS offset:} Pre-measured for the venue and already set in \texttt{test\_position\_fusion.py} and \texttt{main.py}. \textbf{Do not change.}
        \begin{itemize}
            \item \texttt{GPS\_OFFSET\_X\_MM = 609.6}
            \item \texttt{GPS\_OFFSET\_Y\_MM = -304.8}
        \end{itemize}
        \item \textbf{Dead-Reckoning Fallback:} If the ArUco tag is occluded, the system dead-reckons from the last valid GPS fix using the odometry delta.
    \end{itemize}
\end{frame}

\begin{frame}[fragile]{Commands for Fusion Tuning}
    \item \textbf{Terminal 1 (inside Docker) --- start bridge every time:}
    \begin{verbatim}
ros2 run bridge bridge
    \end{verbatim}
    \item \textbf{Terminal 2 (inside Docker) --- run the desired test:}
    \begin{verbatim}
ros2 launch robot test_position_fusion.launch.py
# or
ros2 launch robot test_orientation_fusion.launch.py
    \end{verbatim}
    \item \textbf{Viewing results (outside Docker, in VS Code terminal):}
    \begin{itemize}
        \item Position fusion: image already in \texttt{\textasciitilde/Project-NUEVO/} --- Ctrl-click to open.
        \item Orientation fusion / trajectory: copy first, then Ctrl-click:
    \end{itemize}
    \begin{verbatim}
docker cp docker-ros2_runtime-1:
/root/orientation_fusion_test_result.png ~/Project-NUEVO/
    \end{verbatim}
\end{frame}

\begin{frame}{What to Tune in Each Test}
    \begin{itemize}
        \item \textbf{Position fusion:} edit \texttt{POSITION\_FUSION\_ALPHA} in \texttt{test\_position\_fusion.py}
        \item \textbf{Orientation fusion:} edit \texttt{ORIENTATION\_FUSION\_ALPHA} in \texttt{test\_orientation\_fusion.py}. 
        \item \textbf{Position test workflow:} robot drives 1000~mm straight; saves \texttt{position\_fusion\_test\_result.png} directly to \texttt{\textasciitilde/Project-NUEVO/}.
        \item \textbf{Orientation test workflow:} robot turns 180 degrees; result saved inside Docker --- requires \texttt{docker cp} to view.
        \item \textbf{For the course run:} set \texttt{TAG\_ID} in \texttt{main.py} and tune \texttt{POSITION\_ALPHA} in \texttt{robot.py}.  Everything else can stay at its default.
    \end{itemize}
\end{frame}

\begin{frame}{Key Parameters Reference}
    \begin{tabular}{lll}
        \hline
        \textbf{Parameter} & \textbf{File} & \textbf{Action} \\
        \hline
        \texttt{TAG\_ID} & \texttt{main.py} & Set to your group's assigned tag ID \\
        \texttt{POSITION\_ALPHA} & \texttt{robot.py} & Tune (0.0--1.0); default 0.10 \\
        \texttt{ORIENTATION\_ALPHA} & \texttt{robot.py} & Leave at 0.0 (IMU unreliable) \\
        \texttt{INITIAL\_THETA\_DEG} & \texttt{main.py} & Leave at 90.0 (face $+y$, toward wall) \\
        \texttt{TAG\_X\_OFFSET\_MM} & \texttt{robot.py} & 0.0 if tag centred on axle midpoint \\
        \texttt{TAG\_Y\_OFFSET\_MM} & \texttt{robot.py} & 0.0 if tag centred on axle midpoint \\
        \texttt{IMU\_Z\_DOWN} & \texttt{robot.py} & False (chip faces up); optional \\
        \texttt{GPS\_OFFSET\_X/Y} & \texttt{main.py} & Pre-set --- do not change \\
        \hline
    \end{tabular}

    \vspace{0.4cm}
    \textbf{ArUco tag mounting tips:}
    \begin{itemize}
        \item Mount flat; sides of printed square parallel to robot axes.
        \item Centre tag above the midpoint of the drive-wheel axle line.
        \item Tilt or rotation causes systematic position/heading errors.
    \end{itemize}
\end{frame}

\begin{frame}{Visual Alpha-Tuning Checklist}
    \textbf{Position fusion}
    \begin{itemize}
        \item If fused Y barely corrects back toward the floor markers, raise $\alpha_{\text{pos}}$.
        \item If the fused path snaps sideways or chatters when GPS is active, lower $\alpha_{\text{pos}}$.
        \item Make sure to keep it between the coordinate markers so that GPS sees it. If GPS is never acquired, the run is not useful for alpha tuning.
    \end{itemize}

    \vspace{0.2cm}
    \textbf{Orientation fusion}
    \begin{itemize}
        \item If fused heading nearly matches odometry throughout, $\alpha_{\text{orientation}}$ is too low.
        \item If fused heading is jagged or noisy while odometry is smooth, $\alpha_{\text{orientation}}$ is too high.
        \item A good result keeps the correction bounded and smooth during the spin.
    \end{itemize}
\end{frame}

\begin{frame}{Dead Reckoning vs. Sensor Fusion}
    \centering
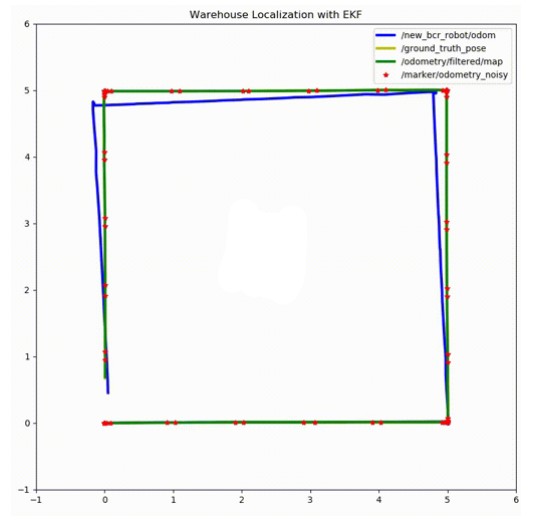
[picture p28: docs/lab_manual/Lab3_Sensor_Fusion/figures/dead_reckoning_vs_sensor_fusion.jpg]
    
    
    \vspace{0.3cm}
    \begin{itemize}
        \item \textbf{Blue:} Robot location based on dead reckoning (drifts over time).
        \item \textbf{Green:} Robot location based on sensor fusion (remains accurate).
    \end{itemize}
\end{frame}

\begin{frame}{Venue Navigation with Pure Pursuit}
    Accurate pose estimation enables the execution of pure-pursuit path planning.
    \vspace{0.3cm}
    \begin{enumerate}
        \item \textbf{Read Fused Pose:} Obtain $(\hat{x}, \hat{y}, \hat{\theta})$ from sensor fusion.
        \item \textbf{Advance Path:} Compare the fused pose against the waypoint list.
        \item \textbf{Compute Lookahead:} Determine the pursuit point on the path ahead of the robot.
        \item \textbf{Command Velocity:} Calculate and send linear and angular velocity commands to correct the cross-track error.
    \end{enumerate}
\end{frame}

\end{document}

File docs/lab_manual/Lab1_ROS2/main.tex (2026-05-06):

\documentclass{ol-softwaremanual}

% Packages used in this example
\usepackage{graphicx}  % for including images
\usepackage{microtype} % for typographical enhancements
\usepackage{amsmath}   % for equations and mathematics
\usepackage{minted}    % for styled code blocks (requires -shell-escape + Pygments)
\usepackage{hyperref}  % for hyperlinks
\usepackage[a4paper,top=4.2cm,bottom=4.2cm,left=3.5cm,right=3.5cm]{geometry}

% Additional packages for lab content
\usepackage{enumitem}
\usepackage{changepage}  % for adjustwidth (wider code blocks)

% Code block style: light gray background, small monospace font, line wrapping
\setminted{style=friendly, bgcolor=gray!10, fontsize=\small, breaklines=true, breakanywhere=true}

% Wider code blocks: extend codemargin into each margin, normal text width unchanged
\newlength{\codemargin}
\setlength{\codemargin}{1.0cm}
\AddToHook{env/minted/before}{%
  \begin{adjustwidth}{-\codemargin}{-\codemargin}%
  \addtolength{\hsize}{2\codemargin}%
}
\AddToHook{env/minted/after}{\end{adjustwidth}}

% Give LaTeX extra inter-word stretch to avoid overfull boxes from long \texttt paths
\setlength{\emergencystretch}{2em}

% Machine-location badges for task headings
%   \onlaptop  — green badge, steps performed on the student laptop
%   \onrpi     — blue badge,  steps performed on the Raspberry Pi
\newcommand{\onlaptop}{%
  \,\colorbox{green!25}{\footnotesize\sffamily\bfseries Laptop}}
\newcommand{\onrpi}{%
  \,\colorbox{blue!20}{\footnotesize\sffamily\bfseries RPi}}
\newcommand{\onui}{%
  \,\colorbox{yellow!50}{\footnotesize\sffamily\bfseries UI (browser)}}

% Machine-context callout used at the start of each Task subsection
%   #1 = machine label text,  #2 = brief description
\newcommand{\machinebox}[2]{%
  \par\noindent
  \colorbox{gray!12}{\parbox{\dimexpr\linewidth-2\fboxsep}{%
    \small\sffamily\textbf{Where to run:} #1 \quad\textbar\quad #2}}%
  \par\smallskip}

% Custom macros used in this example document
\newcommand{\doclink}[2]{\href{#1}{#2}}
\newcommand{\cs}[1]{\texttt{\textbackslash #1}}

% Match original template cover spacing:
%   ~30% whitespace, logo, large gap, title+version, vfill, author+date
\makeatletter
\renewcommand\maketitle{%
  \begin{titlepage}
  \centering
  \vspace*{0.18\textheight}
  \@logocmd\par
  \vspace{0.10\textheight}
  {\huge\bfseries\@title\par}
  \bigskip
  {\Large\@ver\par}
  \vfill
  {\Large\@author\par}
  \@date
  \vspace{0.06\textheight}
  \end{titlepage}
}
\makeatother

% Frontmatter data; appears on title page
\title{Lab 1: ROS2 Introduction and System Integration}
\version{0.1.3}
\author{162 TAs and Maclab members}
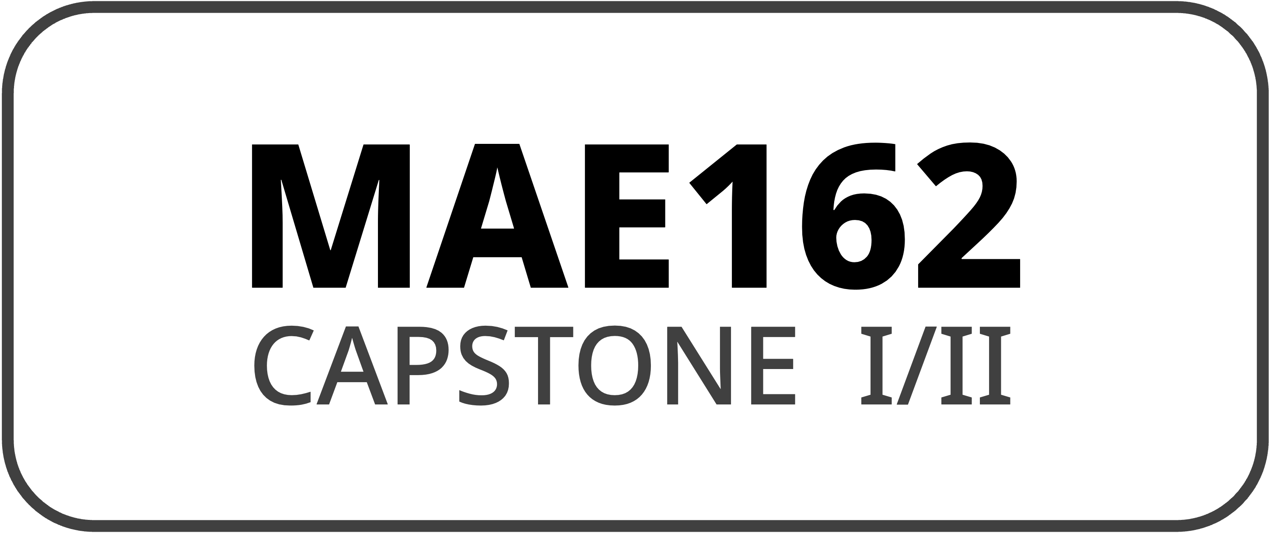
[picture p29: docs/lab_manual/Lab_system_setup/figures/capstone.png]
\softwarelogo{}

\begin{document}

\maketitle

\centerline{\textbf{Warning!}}
\begin{itemize}
    \item No food and drinks are allowed in the lab.
    \item Be careful with the hardware especially the electronics.  Any liquid spill can cause a short circuit, potentially significantly delaying your progress.
    \item Never generate a short circuit.
    \item Connect electric wires only when you are sure about what you are doing.
    \item Be gentle to the buttons! You are liable to the damage made to the robot and its electronics.
    \item Wash your hands after each experiment, some components may contain some lead.
    \item Do not run experiments on the table for the chance the robot may fall on the floor and get damaged.
\end{itemize}
\pagebreak

\tableofcontents
\newpage

\section{System Architecture}

Figure~\ref{fig:system_architecture} shows the full system architecture of Project NUEVO.
The system is divided into several blocks that communicate over well-defined interfaces.
Understanding this structure is essential for debugging and extending the robot.
For a comprehensive reference covering all subsystems, see
\doclink{https://github.com/pochihh/Project-NUEVO/blob/main/docs/manual/MANUAL.md}{\texttt{docs/manual/MANUAL.md}}.

\begin{figure}[h]
  \centering
  
  \caption{System Architecture.}
  \label{fig:system_architecture}
\end{figure}

\subsection*{PCB and Firmware}
The custom PCB hosts an \textbf{Arduino Mega 2560} microcontroller and breaks out
the following hardware channels:

\begin{itemize}
  \item \textbf{4 DC motor channels} with quadrature encoder feedback
  \item \textbf{4 stepper motor channels} (A4988/DRV8825 drivers)
  \item \textbf{16 servo channels} via a PCA9685 I\textsuperscript{2}C PWM controller
  \item \textbf{IMU} (ICM-20948: accelerometer, gyroscope, magnetometer)
  \item \textbf{Voltage monitoring} for the battery rail, 5\,V rail, and servo rail
  \item \textbf{User I/O}: buttons, discrete LEDs, and NeoPixel RGB LEDs
  \item \textbf{Limit switches} and expandable ultrasonic sensor slots
\end{itemize}

The firmware is the only component that directly controls the actuators and reads
hardware encoders; all other layers communicate with it through the bridge.

For full firmware details refer to:
\begin{itemize}
  \item \doclink{https://github.com/pochihh/Project-NUEVO/blob/main/firmware/README.md}{\texttt{firmware/README.md}} --- build, upload, and configuration overview
  \item \doclink{https://github.com/pochihh/Project-NUEVO/blob/main/firmware/arduino/src/config.h}{\texttt{firmware/arduino/src/config.h}} --- all compile-time settings (channel counts, gains, rates)
  \item \doclink{https://github.com/pochihh/Project-NUEVO/blob/main/firmware/docs/architecture.md}{\texttt{firmware/docs/architecture.md}} --- runtime task structure and startup order
  \item \doclink{https://github.com/pochihh/Project-NUEVO/blob/main/docs/COMMUNICATION_PROTOCOL.md}{\texttt{docs/COMMUNICATION\_PROTOCOL.md}} --- TLV protocol, message catalog, and state machine
  \item \doclink{https://github.com/pochihh/Project-NUEVO/blob/main/tlv_protocol/TLV_Payloads.md}{\texttt{tlv\_protocol/TLV\_Payloads.md}} --- exact payload byte layouts and IDs
\end{itemize}

\subsection*{Bridge}
The bridge is a Python process running on the \textbf{Raspberry Pi~5}.
It owns the single UART connection to the Arduino (\texttt{/dev/ttyAMA0} at 200\,kbaud)
and translates between the compact TLV wire protocol and higher-level interfaces.
In addition to the transport layer, the bridge runs a \textbf{FastAPI/WebSocket server}
that serves the NUEVO web UI.
When running inside the ROS2 Docker container, the bridge also publishes and subscribes
to ROS2 topics and services, acting as the boundary between the real-time firmware world
and the robot application layer.

Refer to:
\begin{itemize}
  \item \doclink{https://github.com/pochihh/Project-NUEVO/blob/main/docs/ros2/bridge_runtime.md}{\texttt{docs/ros2/bridge\_runtime.md}} --- bridge architecture, shared runtime model, and reset recovery
  \item \doclink{https://github.com/pochihh/Project-NUEVO/blob/main/docs/COMMUNICATION_PROTOCOL.md}{\texttt{docs/COMMUNICATION\_PROTOCOL.md}} --- TLV protocol, message catalog, and state machine
\end{itemize}

\subsection*{NUEVO UI}
The NUEVO UI is a \textbf{React} web application served by the bridge backend.
It provides a dashboard for testing and monitoring all hardware in real time:
motor speed setpoints and feedback, stepper positions, servo angles, LED color,
user button states, IMU readings, voltage levels, and odometry.
You access it from any browser on the same network by navigating to the
Raspberry Pi's IP address at port~8000.

Refer to:
\begin{itemize}
  \item \doclink{https://github.com/pochihh/Project-NUEVO/blob/main/ros2_ws/README.md}{\texttt{ros2\_ws/README.md}} --- build instructions for the frontend and how to start the bridge that serves the UI
\end{itemize}

\subsection*{Robot Node}
The \texttt{robot} ROS2 package is where high-level \textbf{decision-making and path planning}
code lives.
It subscribes to sensor and state topics published by the bridge, computes motion commands,
and publishes velocity setpoints back to the bridge for execution.
In this lab the robot node is a scaffold; you will extend it in future labs.

\subsection*{Sensor Node}
The \texttt{sensors} ROS2 package handles \textbf{Raspberry Pi--connected sensors}
that are not part of the Arduino firmware, such as GPS receivers and external range sensors
(LiDAR, ultrasonic modules, etc.).
It publishes sensor data as ROS2 topics for the robot node to consume.

\subsection*{Vision Node}
The \texttt{vision} ROS2 package handles the \textbf{camera pipeline and object detection}.
It reads frames from the camera, runs inference (e.g.\ YOLO), and publishes detection results
as ROS2 topics.
The vision dependencies (OpenCV, libcamera, YOLO) are heavier than the rest of the stack
and are added to the Docker image separately.

Refer to the following for the Robot, Sensor, and Vision nodes:
\begin{itemize}
  \item \doclink{https://github.com/pochihh/Project-NUEVO/blob/main/docs/ros2/ros2_nodes_design.md}{\texttt{docs/ros2/ros2\_nodes\_design.md}} --- package layout, design principles, and topic/service naming
  \item \doclink{https://github.com/pochihh/Project-NUEVO/blob/main/ros2_ws/README.md}{\texttt{ros2\_ws/README.md}} --- Docker workflow, node startup order, and ROS2 API overview
\end{itemize}

\subsection*{Why ROS2 and Docker?}
With this architecture, each component has a single responsibility and communicates
through a standardised message-passing system.
Adding a new sensor, planner, or perception algorithm means writing a new node
that subscribes and publishes standard topics --- the rest of the system does not change.
Docker ensures that every team member and every Raspberry Pi runs the \emph{exact same}
software environment regardless of the host operating system, eliminating
``it works on my machine'' problems and making deployment to the robot a one-command step.

\section{ROS2 Introduction}

\subsection{Core Concepts}

ROS2 (Robot Operating System~2) is an open-source middleware framework for building
robot software.
Despite the name it is not an operating system: it is a set of libraries, tools, and
conventions that run on top of a standard OS and let independently developed programs
communicate with each other cleanly.

\textbf{Nodes} are the basic executable units.
Each node is a process (or a thread within a process) that performs one focused task ---
reading a sensor, running a controller, publishing odometry.
In this project: \texttt{bridge}, \texttt{robot}, \texttt{sensor\_node}, and
\texttt{vision\_node} are each a separate node.

\textbf{Topics} are named communication channels that carry a stream of messages.
A node that produces data \emph{publishes} to a topic; a node that needs that data
\emph{subscribes} to it.
Topics are asynchronous and many-to-many.
For example, the bridge node publishes DC motor state on \texttt{/dc\_state\_all}
and the robot node subscribes to that topic.

\textbf{Messages} define the data structure for a topic.
They are declared in \texttt{.msg} files inside the \texttt{bridge\_interfaces} package
and compiled into language-specific code automatically.
\texttt{bridge\_interfaces/msg/DCStateAll} and \texttt{bridge\_interfaces/msg/SystemPower}
are examples used in this project.

\textbf{Services} are synchronous request--reply interactions.
A node that handles a service advertises it; another node calls it and waits for
a response.
Use services for discrete operations where you need to know whether the action
succeeded.
In this project, firmware state transitions (IDLE $\to$ RUNNING, triggering an E-stop)
use the \texttt{/set\_firmware\_state} service.

\textbf{Packages} are the unit of organisation and distribution.
A package groups related nodes, message definitions, and launch files.
This project has five packages:
\texttt{bridge\_interfaces} (message/service definitions),
\texttt{bridge} (ROS wrapper around the firmware bridge),
\texttt{robot} (motion planning),
\texttt{sensors} (Pi-side sensors), and
\texttt{vision} (camera and detection).

\medskip
\noindent\textit{Keywords for further learning:}
ROS2 publisher/subscriber, colcon build, \texttt{ros2 topic echo}, \texttt{ros2 node info},
QoS policies, launch files, parameter server, tf2 transforms, RViz2, rqt.

\subsection{Docker for ROS2}

Modern robots are developed by teams working on different machines with different
operating systems --- macOS, Windows, Ubuntu.
ROS2 Jazzy officially targets Ubuntu 24.04; running it natively on macOS or Windows
requires significant manual setup that is fragile and hard to reproduce.
Docker solves this by packaging the entire ROS2 environment --- OS libraries,
ROS installation, workspace build --- into a single \emph{container image}.
Everyone on the team starts the same image, so the software environment is
\emph{identical} whether you are developing on a laptop or deploying to the Raspberry Pi.
This also means updating the environment is a \texttt{docker compose build} rather than
a multi-step manual procedure.

In this project the Docker image contains ROS2 Jazzy, the project workspace,
and all Python runtime dependencies.
Two compose files are provided:

\begin{itemize}
  \item \texttt{ros2\_ws/docker/docker-compose.rpi.yml} --- for the Raspberry Pi with real hardware
  \item \texttt{ros2\_ws/docker/docker-compose.vm.yml} --- for macOS / Windows development (mock bridge)
\end{itemize}

\noindent\textit{Keywords for further learning:}
Dockerfile, Docker image vs.\ container, \texttt{docker compose}, volume mounts,
container networking, \texttt{docker exec}, base images.

\section{Raspberry Pi Safety and Usage}

The Raspberry Pi~5 is the compute brain of your robot.
A damaged or corrupted RPi means your whole team is blocked until it is
re-imaged or replaced --- which can take an entire lab session.
The failures we see most often are \emph{entirely preventable}.
Read this section before touching the hardware.

\subsection*{Power}

\begin{itemize}
  \item \textbf{Two valid power sources:}
        \begin{itemize}
          \item \textbf{Supplied USB-C PD adapter} (5\,V / 5\,A) --- use this
                at your bench when the robot battery is not connected.
          \item \textbf{Robot battery via the PCB} --- the PCB's onboard 5\,V
                rail is rated at 6\,A and includes a hot-swap circuit that
                safely switches between battery and bench supply.
                This is the intended power source when the robot is running
                autonomously.
        \end{itemize}
  \item \textbf{Never use a phone charger, laptop USB port, or cheap power bank.}
        These cannot supply enough current; the resulting voltage drop causes
        random crashes and SD card corruption.
  \item \textbf{Never wire the battery directly to the RPi}, bypassing the PCB.
        The PCB regulator and hot-swap circuit are there for a reason.
  \item \textbf{Never hot-swap the SD card.}
        If the card must be removed, shut down first (see below).
\end{itemize}

\subsection*{Shutdown procedure --- the most important habit}

The RPi runs a Linux filesystem.
Pulling the power while the OS is writing to the SD card --- which happens
constantly in the background --- \textbf{corrupts the filesystem}.
A corrupted SD card requires a full re-image and you lose all local work that
was not pushed to GitHub.

\medskip
\noindent\textbf{Always shut down properly before removing power:}

\begin{minted}{bash}
sudo shutdown -h now
\end{minted}

Wait for the green activity LED to stop blinking and go dark (roughly 10--15\,s),
\emph{then} unplug the power cable.
This also applies when you are finished for the day and when packing up the robot.

\subsection*{GPIO pins}

\begin{itemize}
  \item \textbf{GPIO logic level is 3.3\,V.}
        The RPi is \emph{not} 5\,V tolerant on its GPIO pins.
        Connecting a 5\,V signal directly to any GPIO pin will destroy that
        pin and may kill the entire SoC.
        Always use a level shifter or voltage divider when interfacing with
        5\,V peripherals.
  \item \textbf{Maximum current per GPIO pin is 16\,mA} (8\,mA recommended).
        Never drive an LED, motor, or relay directly from a GPIO pin without a
        current-limiting resistor or driver IC.
  \item \textbf{Never short GPIO pins together}, and keep metal objects (tools,
        loose wires, PCB offcuts) away from the board when it is powered.
        A momentary short across the wrong pins can instantly destroy the board.
  \item \textbf{Ground yourself} before handling the board.
        Touch a grounded metal surface (e.g.\ a PC chassis) or wear an ESD
        wrist strap.
        Electrostatic discharge is invisible and silent --- and permanently damages
        chips.
\end{itemize}

\subsection*{Physical handling}

\begin{itemize}
  \item Hold the board by its edges.
        Finger pressure on chips or connectors can crack solder joints.
  \item Keep the board on a \textbf{non-conductive surface} (the anti-static bag it came
        in, or a plastic tray).
        Placing it on a metal bench or a conductive surface shorts the bottom
        pads.
  \item Do not stack anything on top of the RPi when it is running.
        The processor generates significant heat; blocking airflow causes thermal
        throttling and instability.
\end{itemize}

\subsection*{SD card hygiene}

\begin{itemize}
  \item \textbf{Push your work to GitHub immediately.}
        SD cards have a finite write endurance and \emph{will} eventually fail.
        Any work that only exists on the RPi can vanish at any time (see also
        Task~1.3).
  \item Avoid running \texttt{apt upgrade} or long package installs when the
        robot is on battery --- a power cut mid-upgrade corrupts the package
        database and often requires a re-image.
  \item If the RPi fails to boot, do \emph{not} keep trying to power-cycle it.
        Note down any error messages on the HDMI output or status LEDs and ask
        the TAs for help.
\end{itemize}

\section{Lab Activities}

\subsection{Task 1: Set Up Your Repository}\label{sec:task1}

\machinebox{\onlaptop\ your laptop \textbar\ \onrpi\ Raspberry Pi}{The repo must be cloned on \emph{both} machines. Your laptop uses it for firmware (Task~\ref{sec:task2}); the RPi uses it for ROS2 (Task~\ref{sec:task3}). Day-to-day edits are made on your laptop, then pulled onto the RPi.}

In this course you will modify the Project NUEVO codebase to add features and
tune your robot.
Each team should work in their own copy of the repository so that your changes
do not affect other teams and so you can safely experiment.

\subsubsection{Fork the Repository\onlaptop}

\begin{enumerate}
  \item Go to \doclink{https://github.com/pochihh/Project-NUEVO}{github.com/pochihh/Project-NUEVO}.
  \item Click \textbf{Fork} (top-right corner) to create a copy under your own GitHub account.
    \hfill\textit{(keyword: fork)}
  \item On your forked repository page, go to \textbf{Settings $\to$ Collaborators}
        and add your teammates as collaborators so everyone can push to the same fork.
    \hfill\textit{(keyword: collaborators, repository permissions)}
\end{enumerate}

\subsubsection{Clone the Repository --- Laptop\onlaptop}

Clone your fork onto your laptop.
You will use this copy to edit firmware, run MATLAB, and push changes to GitHub.

\begin{minted}{bash}
git clone https://github.com/<your-username>/Project-NUEVO.git
cd Project-NUEVO
\end{minted}
\hfill\textit{(keyword: clone, remote)}

\subsubsection{Clone the Repository --- Raspberry Pi\onrpi}\label{ssec:clone-rpi}

SSH into the Raspberry Pi and clone the \emph{same fork} there.
The RPi copy is what Docker mounts when running the ROS2 workspace in Task~\ref{sec:task3}.

\begin{minted}{bash}
git clone https://github.com/<your-username>/Project-NUEVO.git
cd Project-NUEVO
\end{minted}

\noindent You do not normally edit code directly on the RPi.
The typical workflow is: edit on your laptop $\to$ commit $\to$ push to GitHub
$\to$ \texttt{git pull} on the RPi to bring in the latest changes.
You can make local changes on the RPi and push them back to GitHub if needed,
but be careful not to let the two clones diverge---always pull on one machine
before editing, and push promptly so your teammates stay in sync.

\noindent\textbf{Important:} the Raspberry Pi is embedded hardware and can lose
power unexpectedly, suffer SD card corruption, or need to be re-imaged at any
time. Any work that exists \emph{only} on the RPi can be lost without warning.
\textbf{Push every change to GitHub as soon as you make it.}
Never leave uncommitted or unpushed work sitting on the RPi.

\subsubsection{Daily Git Workflow\onlaptop}

Git lets your whole team work on the same codebase simultaneously.
Run these commands on your laptop:

\begin{enumerate}
  \item \textbf{Stage} the files you want to save.
\begin{minted}{bash}
git add <filename>
\end{minted}
        \hfill\textit{(keyword: staging area, working tree)}

  \item \textbf{Commit} to record a snapshot with a short message describing what you did.
\begin{minted}{bash}
git commit -m "brief description of change"
\end{minted}
        \hfill\textit{(keyword: commit, commit message)}

  \item \textbf{Push} to upload your commits to GitHub so teammates (and the RPi) can see them.
\begin{minted}{bash}
git push
\end{minted}
        \hfill\textit{(keyword: push, origin)}

  \item \textbf{Pull} to download your teammates' latest commits before you start working.
\begin{minted}{bash}
git pull
\end{minted}
        \hfill\textit{(keyword: pull, merge, rebase, merge conflict)}
\end{enumerate}

\subsubsection{Pull Updates from the Original Repository\onlaptop}

Bug fixes and new features will be released to the original repository during the
course.
To bring them into your fork, add the original repository as a second remote and
pull from it:

\begin{enumerate}
  \item Add the original repository as the \texttt{upstream} remote (one-time setup):
\begin{minted}{bash}
git remote add upstream https://github.com/pochihh/Project-NUEVO.git
\end{minted}
        \hfill\textit{(keyword: remote, upstream)}

  \item Fetch and merge the latest changes from upstream into your local branch (for updates \textbf{in the future}):
\begin{minted}{bash}
git fetch upstream
git merge upstream/main
\end{minted}
        \hfill\textit{(keyword: fetch, merge, fast-forward)}

  \item Push the merge result (the updates) to your fork:
\begin{minted}{bash}
git push
\end{minted}
\end{enumerate}

\subsection{Task 2: Flash the Firmware}\label{sec:task2}

\machinebox{\onlaptop\ your laptop}{Arduino IDE is installed on your laptop; the Arduino is connected via USB.}

The Arduino Mega firmware must be flashed onto the robot before the bridge can
communicate with it.
Full details and troubleshooting are in
\doclink{https://github.com/pochihh/Project-NUEVO/blob/main/firmware/README.md}{\texttt{firmware/\allowbreak README.md}}.

\subsubsection{Prerequisites\onlaptop}

\begin{enumerate}
  \item Install \textbf{Arduino IDE 2.x} and the \textbf{Arduino AVR Boards} core.
  \item Increase the serial buffer size so the firmware UART link does not overflow.
        Create or edit (if exists already) \texttt{platform.local.txt} for the installed AVR core and add the following text in it:
\begin{minted}{text}
compiler.cpp.extra_flags=-DSERIAL_RX_BUFFER_SIZE=512 -DSERIAL_TX_BUFFER_SIZE=256
\end{minted}
        Typical file locations (replace \texttt{1.8.7} with your installed AVR core version):

        \textit{macOS:}
\begin{minted}{text}
~/Library/Arduino15/packages/arduino/hardware/avr/1.8.7/platform.local.txt
\end{minted}
        \textit{Windows:}
\begin{minted}{text}
C:\Users\<your-user>\AppData\Local\Arduino15\packages\arduino\hardware\avr\1.8.7\platform.local.txt
\end{minted}
\end{enumerate}

\subsubsection{Build and Upload\onlaptop}

\begin{enumerate}
  \item Open \texttt{firmware/arduino/arduino.ino} in Arduino IDE.
  \item Select board: \textbf{Arduino Mega or Mega~2560}.
  \item Select the correct COM / serial port for the connected Arduino.
  \item Click \textbf{Verify} to confirm the firmware compiles without errors.
  \item Click \textbf{Upload} to flash the firmware onto the board.
\end{enumerate}

After a successful upload the board resets and the firmware starts running.
Confirm by opening the Arduino IDE Serial Monitor at 115\,200 baud and checking
for heartbeat output.

\subsection{Task 3: Bring Up the ROS2 Environment and NUEVO UI}\label{sec:task3}

\machinebox{\onrpi\ Raspberry Pi (SSH or direct terminal)}{Most steps run on the RPi. The final step (Access the NUEVO UI) opens in a browser on any device on the same network. Make sure you have already cloned your fork on the RPi (Section~\ref{ssec:clone-rpi}) and run \texttt{git pull} to get the latest code before starting.}

In this task you will start the Docker container on the Raspberry Pi, launch the
bridge node, and verify all hardware using the NUEVO web UI.
Full setup details are in
\doclink{https://github.com/pochihh/Project-NUEVO/blob/main/ros2_ws/README.md}{\texttt{ros2\_ws/README.md}}.

\subsubsection{Raspberry Pi UART Setup (one-time)\onrpi}

The bridge communicates with the Arduino over the RPi hardware UART.
Enable it by editing the RPi boot configuration files:

\begin{enumerate}
  \item Add the following lines to \texttt{/boot/firmware/config.txt}:
\begin{minted}{text}
enable_uart=1
dtoverlay=uart0-pi5
\end{minted}

  \item Remove any \texttt{console=serial0} or \texttt{console=ttyAMA0} entries
        from \texttt{/boot/firmware/cmdline.txt} so the OS does not claim the port.

  \item Reboot and verify: \texttt{ls -l /dev/ttyAMA0} should show a character
        device owned by the \texttt{dialout} group.
\end{enumerate}

\subsubsection{Install Node.js and npm (one-time)\onrpi}

The NUEVO UI frontend build uses \texttt{npm}. Install Node.js and npm on the
Raspberry Pi host first:

\begin{minted}{bash}
sudo apt update
sudo apt install -y nodejs npm
node -v
npm -v
\end{minted}

For this project, \texttt{node -v} should report a reasonably modern version
(Node 18 or newer is a safe baseline).

\subsubsection{Build the Frontend (one-time)\onrpi}

The bridge serves the NUEVO web UI as a pre-built static bundle.
Build it once from the repository root:

\begin{minted}{bash}
cd nuevo_ui/frontend
npm ci
npm run build
cd ../..
cp -r nuevo_ui/frontend/dist/. nuevo_ui/backend/static/
\end{minted}

\subsubsection{Install Docker (one-time)\onrpi}

For this class project, the simplest Docker setup on the Raspberry Pi is the
official Docker convenience script:

\begin{minted}{bash}
curl -fsSL https://get.docker.com -o get-docker.sh
sudo sh get-docker.sh
sudo usermod -aG docker $USER
newgrp docker
docker --version
docker compose version
\end{minted}

\textbf{Note:} if \texttt{newgrp docker} does not take effect cleanly in your
shell, log out and log back in once, then re-run the version checks above.

\subsubsection{Start the Docker Container\onrpi}

From the repository root on the Raspberry Pi:

\begin{minted}{bash}
COMPOSE=ros2_ws/docker/docker-compose.rpi.yml
docker compose -f $COMPOSE build
docker compose -f $COMPOSE up -d
docker compose -f $COMPOSE logs -f ros2_runtime
\end{minted}

Wait until the log shows that \texttt{colcon build} finished and the container is ready.

\subsubsection{Launch the Bridge Node\onrpi}

Open a shell inside the running container and start the bridge:

\begin{minted}{bash}
docker compose -f $COMPOSE exec ros2_runtime bash
source /opt/ros/jazzy/setup.bash
source /ros2_ws/install/setup.bash
ros2 run bridge bridge
\end{minted}

The bridge node connects to the Arduino, starts the WebSocket server, and begins
publishing ROS2 topics.

\subsubsection{Access the NUEVO UI\onui}

Open a browser on any device on the same network and navigate to:
\begin{center}
  \texttt{http://<raspberry-pi-ip>:8000}
\end{center}

Login credentials: username \texttt{user}, password \texttt{162}.
\textbf{Change your password after first login.}

Use the UI to test each hardware feature:
\begin{itemize}
  \item Set stepper motor positions and verify movement.
  \item Command servo angles and observe the mechanical response.
  \item Change LED colors via the colour picker.
  \item Press each user button and confirm the indicator updates.
  \item Check IMU readings (accelerometer, gyroscope) for expected values.
  \item Monitor the battery voltage level on the power panel.
\end{itemize}

\subsection{Task 4: DC Motor PI Tuning and Step Response}\label{sec:task4}

\machinebox{\onlaptop\ your laptop \textbar\ \onui\ NUEVO UI \textbar\ \onrpi\ RPi}{MATLAB analysis and gain calculations run on your laptop. Motor commands and data recording use the NUEVO UI in your browser. The RPi must be running the bridge node from Task~\ref{sec:task3}.}

In this task you will tune the PI velocity controller for one DC motor and record
step responses to evaluate your design.
The goal is to transition from the default gains to a set of gains that you can
justify from a simple model of the motor dynamics.

\subsubsection{Model-Based PI Design (Optional)\onui\onlaptop}\label{ssec:model-pi}

A DC motor's velocity dynamics can be approximated as a first-order linear system:
\begin{equation}
  G(s) = \frac{K}{\tau s + 1}
  \label{eq:motor_model}
\end{equation}
where $K$ is the steady-state gain (ticks/s per PWM unit) and $\tau$ is the time
constant (seconds).
You can identify both parameters from an open-loop step response.

\paragraph{Step 1: Measure the open-loop step response.}
In the NUEVO UI, switch the motor to \textbf{PWM mode} and apply a step change in
PWM from 0 to a fixed value (e.g.\ 128 out of 255, or about 50\,\%).
Record the velocity $\omega(t)$ response using the UI's plot feature.

From the recorded curve:
\begin{itemize}
  \item $K = \omega_{ss} / u$ \quad where $u$ is the \emph{actual integer PWM value you
        applied} (0--255, \emph{not} 1).
        For example, if you applied PWM\,=\,128 and the motor settled at
        $\omega_{ss} = 980$\,ticks/s, then $K = 980/128 \approx 7.66$\,ticks/s per PWM
        unit.
  \item $\tau$ = the time at which $\omega(t)$ first reaches $63.2\,\%$ of $\omega_{ss}$
        (read directly from the step-response plot).
\end{itemize}
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

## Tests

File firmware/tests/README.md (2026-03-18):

# Firmware Test Sketches

Each subdirectory is a standalone Arduino sketch that exercises one subsystem. Upload a test sketch the same way you upload the main firmware — select **Arduino Mega 2560**, choose the port, and click Upload. Open the **Serial Monitor at 115200 baud** unless noted otherwise.

## The `src` Symlink

The Arduino IDE requires all source files to be inside the sketch directory. Every test folder contains a `src` symlink pointing to the shared firmware source at `firmware/arduino/src/`. Create it after cloning:

```bash
# macOS / Linux
cd firmware/tests
for dir in test_*/; do
    ln -sf ../../arduino/src "$dir/src"
done
```

```powershell
# Windows — run PowerShell as Administrator
cd firmware\tests

$target = Resolve-Path "..\arduino\src"
Get-ChildItem -Directory -Filter "test_*" | ForEach-Object {
    $link = Join-Path $_.FullName "src"
    if (Test-Path $link) {
        Remove-Item $link -Force
    }
    New-Item -ItemType Junction -Path $link -Target $target
}
```

Verify: `ls -la firmware/tests/test_scheduler/src` should show `src -> ../../arduino/src`.

---

## Test Index

| Test | Phase | What it tests |
|---|---|---|
| [test_scheduler](#test_scheduler) | 1 | Timer1 1 kHz cooperative scheduler |
| [test_uart_tlv](#test_uart_tlv) | 2 | TLV v2.0 protocol, MessageCenter state machine |
| [test_uart_rx_10khz](#test_uart_rx_10khz) | 2 | UART RX via 10 kHz drain + 100 Hz decode (ISR path) |
| [test_encoder](#test_encoder) | 3 | Quadrature encoder counting (2x/4x), direction |
| [test_dc_motor_pwm](#test_dc_motor_pwm) | 3 | H-bridge direct PWM + encoder readback |
| [test_dc_motor_pid](#test_dc_motor_pid) | 3 | Closed-loop PID velocity and position control |
| [test_current_sensing](#test_current_sensing) | 3 | ADC current sensor, per-motor current feedback |
| [test_servo](#test_servo) | 4 | PCA9685 I2C PWM controller, 16-channel servo |
| [test_stepper](#test_stepper) | 4 | Timer3 stepper pulse generation, trapezoidal profile |
| [test_voltage](#test_voltage) | 5 | ADC battery/rail voltage monitoring |
| [test_user_io](#test_user_io) | 5 | Buttons, PWM LEDs, NeoPixel patterns |
| [test_eeprom](#test_eeprom) | 5 | EEPROM read/write, power-cycle persistence |
| [test_i2c_scanner](#test_i2c_scanner) | — | I2C bus scan utility |

---

## test_scheduler

**Subsystem:** Scheduler (Timer1 @ 1 kHz)
**Hardware:** No external hardware needed (uses on-board LEDs)

Registers four LED tasks at different rates and verifies that each fires at the right interval. Optional oscilloscope pins (A9, A10) let you measure the scheduler tick with a scope.

**Expected output:** LEDs blink at their programmed rates. Serial Monitor shows initialization; no further output unless `DEBUG_SCHEDULER` is uncommented.

| LED | Rate |
|-----|---|
| LED_GREEN | 2 Hz |
| LED_BLUE | 1 Hz |
| LED_ORANGE | 0.5 Hz |
| LED_RED | heartbeat pulse every 5 s |

---

## test_uart_tlv

**Subsystem:** MessageCenter, TLV v2.0 protocol
**Hardware:** None required for compile verification; Serial2 loopback (pin 16 → 17) or RPi/PC for protocol testing

Initializes MessageCenter and runs `processIncoming()` + `sendTelemetry()` at 100 Hz via the scheduler. Prints system state and liveness status to USB Serial at 1 Hz.

**State machine summary:**

| Command | type | cmd | Transition |
|---|---|-----|---|
| SYS_CMD_START | 3 | 1 | IDLE → RUNNING |
| SYS_CMD_STOP | 3 | 2 | RUNNING → IDLE |
| SYS_CMD_RESET | 3 | 3 | ERROR/ESTOP → IDLE |
| SYS_CMD_ESTOP | 3 | 4 | any → ESTOP |

- **IDLE:** only SYS_STATUS sent (1 Hz)
- **RUNNING:** full telemetry on Serial2 up to 100 Hz
- **Liveness timeout:** 500 ms without any TLV — actuators disabled

**Loopback test:** connect pin 16 (TX2) → pin 17 (RX2). Outgoing packets loop back and reset the liveness timer, so State stays IDLE and Liveness shows "OK".

---

## test_uart_rx_10khz

**Subsystem:** MessageCenter RX (Timer3 drain + Timer4 decode)
**Hardware:** RPi or PC sending TLV heartbeat frames on Serial2

Replicates the main firmware RX architecture exactly:
- **TIMER3 @ 10 kHz:** drains Serial2 HW FIFO into MessageCenter ring buffer
- **TIMER4 @ 100 Hz:** runs `MessageCenter::uartTask()` (decode + heartbeat)

Use this to debug missing bytes or framing errors. The sketch prints a 1 Hz status line:
`hb` (heartbeat validity), `last` (ms since last TLV), `rxErr` (decode errors),
and ISR counters (`t3`, `t4`, `task`).

Key toggles (at the top of the sketch):
- `TEST_UART_NESTED_INTERRUPTS` — enable nested interrupts inside TIMER3
- `TEST_UART_USE_STEPPER_ISR` — include stepper ISR load at 10 kHz
- `TEST_UART_DECODE_IN_ISR` — decode in ISR vs main loop

---

## test_encoder

**Subsystem:** EncoderCounter (2x/4x quadrature)
**Hardware:** DC motors with encoders connected (encoder power only — no motor power needed)

Initializes all four encoder channels and prints counts + last-edge timestamps at 5 Hz. Manually rotate the motor shafts to verify counts increment/decrement in the correct direction.

**Verify:**
- Forward rotation → count increases
- Backward rotation → count decreases
- Count resolution = `ENCODER_PPR × mode_multiplier` per revolution

---

## test_dc_motor_pwm

**Subsystem:** DCMotor pin interface, EncoderCounter
**Hardware:** Motors with H-bridge connected, motor power supply, encoders

Cycles motors 1 and 2 through: Forward (25% PWM) → Brake → Reverse (25% PWM) → Brake every 2 seconds. Prints encoder counts at 5 Hz to confirm the encoders track motion and direction.

**Start conservatively:** the default PWM is 25% (64/255). Adjust `TEST_PWM_FORWARD` / `TEST_PWM_REVERSE` if needed.

---

## test_dc_motor_pid

**Subsystem:** DCMotor closed-loop control, PID, VelocityEstimator
**Hardware:** Motors 1 & 2 with encoders, motor power supply; shafts free to spin

Automatically sequences through five test states (5 seconds each):

| State | What happens |
|---|---|
| Velocity +500 t/s | Motor tracks 500 ticks/sec forward |
| Velocity −500 t/s | Motor tracks 500 ticks/sec reverse |
| Velocity 0 | Motor holds zero (braking) |
| Position +720 ticks | Motor moves to +720 ticks (≈1 rev in 2x mode) |
| Position −720 ticks | Motor moves to −720 ticks |

Prints position, velocity, PWM output, and current at 5 Hz. Tune `DEFAULT_VEL_KP/KI/KD` and `DEFAULT_POS_KP/KI/KD` in `config.h` if tracking is poor.

---

## test_current_sensing

**Subsystem:** ADC current sensing (CT pins)
**Hardware:** Motors 1–4 connected with current sensors (CT pins A3–A6), motor power supply

Interactive test. Select a motor with `1`–`4`, then command forward/reverse/stop or an automatic PWM sweep. Prints raw ADC, voltage, and current (mA) at 10 Hz.

| Key | Action |
|-----|---|
| `1`–`4` | Select motor |
| `f` | Forward at current PWM |
| `r` | Reverse at current PWM |
| `s` | Stop |
| `a` | Auto sweep: 0 → 50 → 100 → 150 → 200 → 255 PWM |
| `5` | Set PWM = 128 (50%) |
| `6`–`9` | Set PWM proportional to key |
| `u` | Toggle bipolar offset (2.5 V at 0 A) |
| `n` | Toggle noise filtering |
| `h` | Help |

---

## test_servo

**Subsystem:** ServoController (PCA9685 I2C)
**Hardware:** PCA9685 on I2C bus (SDA=20, SCL=21), servo(s) connected, servo power supply

Interactive test for all 16 PCA9685 channels.

| Command | Action |
|---|---|
| `e` | Enable servo outputs (global OE) |
| `d` | Disable servo outputs |
| `s<ch>,<us>` | Set channel to pulse width in µs (e.g., `s0,1500`) |
| `a<ch>,<deg>` | Set channel to angle in degrees (e.g., `a0,90`) |
| `c<ch>` | Center channel (1500 µs) |
| `w<ch>` | Sweep single channel back and forth |
| `W` | Sweep all 16 channels |
| `0`–`9`, `A`–`F` | Quick-center channel 0–15 |
| `?` | Print status |
| `help` | Show command list |

---

## test_stepper

**Subsystem:** StepperManager, StepperMotor (Timer3 @ 10 kHz)
**Hardware:** Stepper driver(s) (A4988/DRV8825), stepper motor(s); optional limit switch(es)

Interactive test for all four stepper channels. Timer3 runs at 10 kHz for pulse generation. Status auto-prints every 2 seconds.

| Command | Action |
|---|---|
| `e<id>` | Enable stepper (0–3) |
| `d<id>` | Disable stepper |
| `m<id>,<steps>` | Move relative steps (e.g., `m0,200`) |
| `p<id>,<pos>` | Move to absolute position (e.g., `p0,0`) |
| `v<id>,<vel>` | Set max velocity in steps/sec |
| `a<id>,<accel>` | Set acceleration in steps/sec² |
| `h<id>,<dir>` | Home stepper (dir: `1` or `-1`) |
| `s<id>` | Emergency stop one stepper |
| `S` | Emergency stop all steppers |
| `?` or `help` | Status / command list |

Default parameters: 1000 steps/sec velocity, 500 steps/sec² acceleration.

---

## test_voltage

**Subsystem:** SensorManager voltage monitoring (ADC)
**Hardware:** Battery and power rails connected; voltage dividers on A0 (battery), A1 (5 V), A2 (servo)

Prints battery, 5 V rail, and servo rail voltages in a table at 1 Hz. Compare against a multimeter to verify calibration.

| Key | Action |
|-----|---|
| `r` | Print raw ADC values |
| `s` | Print battery noise statistics (over last 10 samples) |
| `c` | Calibration instructions |
| `h` | Help |

Divider ratios are in `config.h` (`VBAT_DIVIDER_RATIO`, `V5_DIVIDER_RATIO`, `VSERVO_DIVIDER_RATIO`). Adjust if readings differ from multimeter by more than ±5%.

---

## test_user_io

**Subsystem:** UserIO (buttons, LEDs, NeoPixel)
**Hardware:** 2 on-board buttons, 5 LEDs (pins 44–47 + LED_RED), NeoPixel WS2812B (pin 42)

Runs a startup LED sweep (each LED on for 500 ms), then enters interactive mode. Buttons also work: BTN1–5 toggle LEDs, BTN6–9 cycle NeoPixel colors, BTN10 turns all LEDs off.

**LED commands** (letters select LED: `r`=RED, `g`=GREEN, `b`=BLUE, `o`=ORANGE, `p`=PURPLE):

| Command | Action |
|---|---|
| `r1` / `r0` | RED LED on / off |
| `rb` | RED LED blink |
| `rt` | RED LED breathe |
| `n<0–7>` | NeoPixel color: 0=off 1=red 2=green 3=blue 4=yellow 5=cyan 6=magenta 7=white |
| `s<0–3>` | System status: 0=OK 1=BUSY 2=WARNING 3=ERROR |
| `?` / `h` | Status / help |

---

## test_eeprom

**Subsystem:** PersistentStorage (EEPROM)
**Hardware:** No external hardware needed

Demonstrates EEPROM non-volatility across power cycles.

**Run 1** (storage uninitialised): writes test values (wheel diameter, wheel base, mag offsets), verifies immediate read-back, then prompts you to power off the Arduino.

**Run 2** (after power cycle): reads the values back and confirms they survived.

| Key | Action |
|-----|---|
| `d` | Dump raw EEPROM bytes with field annotations |
| `r` | Erase all stored data (next boot = Run 1) |
| `w` | Write test values again |
| `h` | Help |

---

## test_i2c_scanner

**Subsystem:** I2C bus (Wire library)
**Hardware:** I2C devices on SDA (pin 20) / SCL (pin 21)

Scans addresses 0x01–0x7F and prints any that respond. Runs once on boot; reset the Arduino to scan again.

**Expected addresses:**

| Address | Device |
|---|---|
| 0x40 | PCA9685 PWM controller |
| 0x68 | ICM-20948 IMU |
| 0x70 | PCA9685 ALL_CALL (broadcast, normal) |
| 0x62 | Garmin LIDAR-Lite v4 (default) |
| 0x00–0x7F | Any other Qwiic device on the bus |

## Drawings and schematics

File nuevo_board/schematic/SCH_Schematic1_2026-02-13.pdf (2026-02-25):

# Power Input

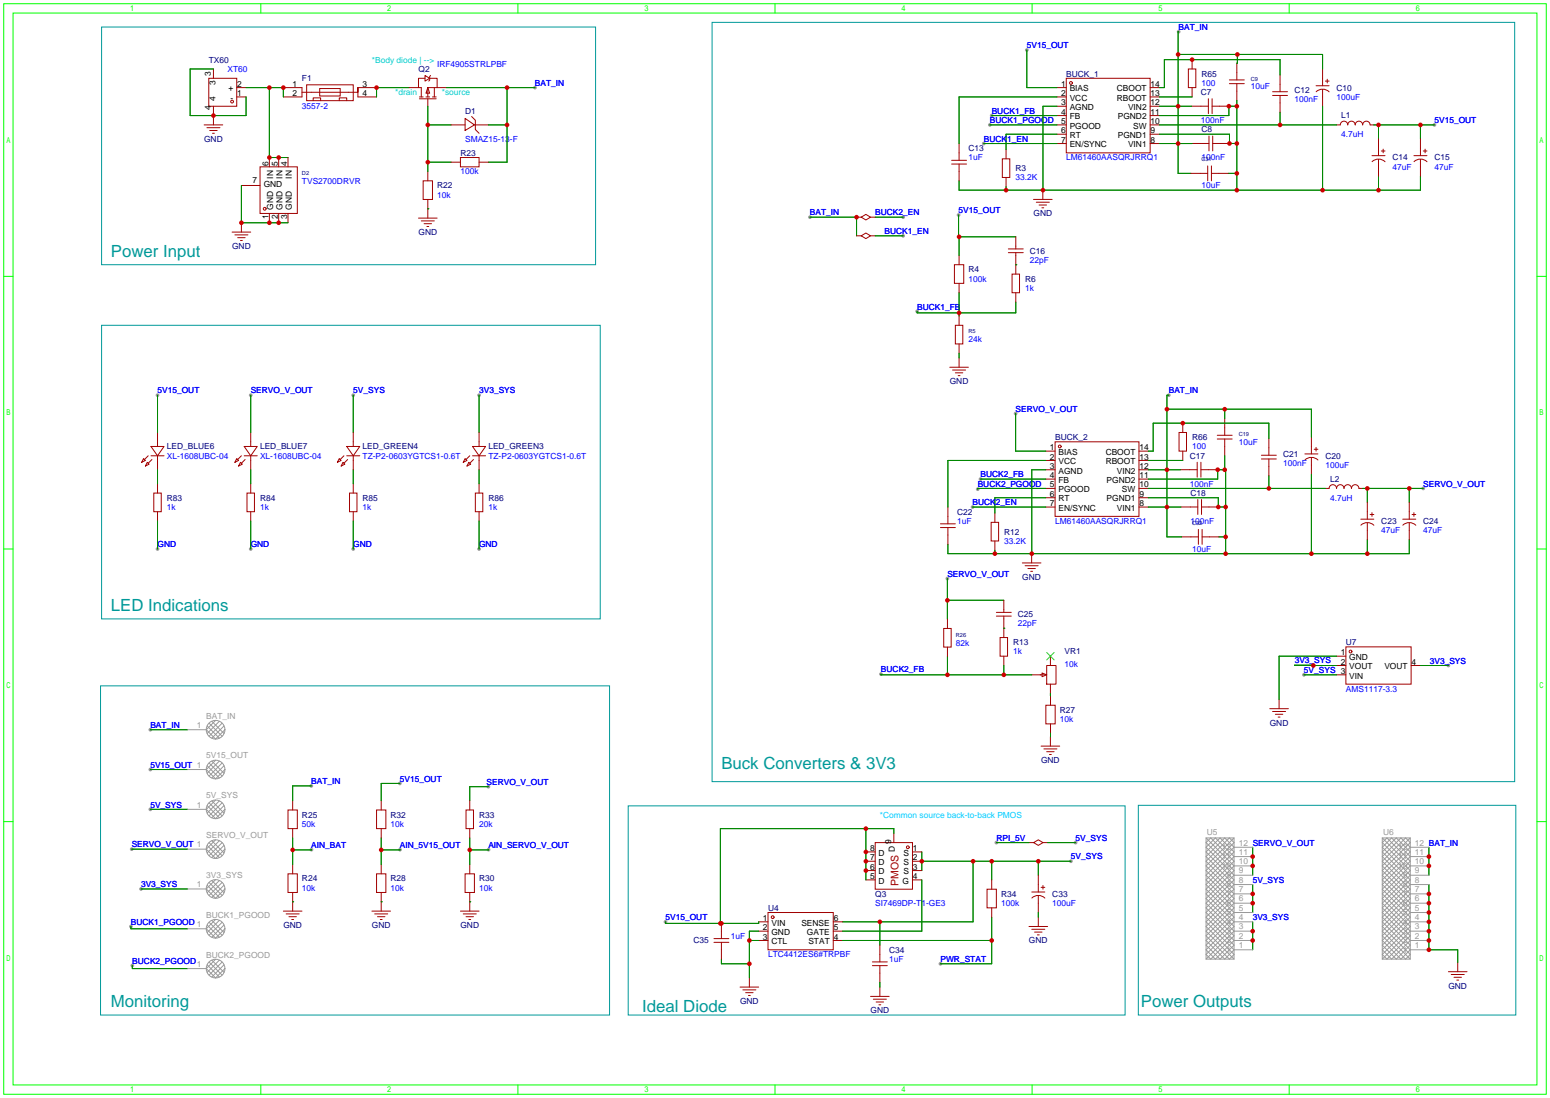
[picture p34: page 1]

*Common source back-to-back PMOS

Power Outputs Ideal Diode

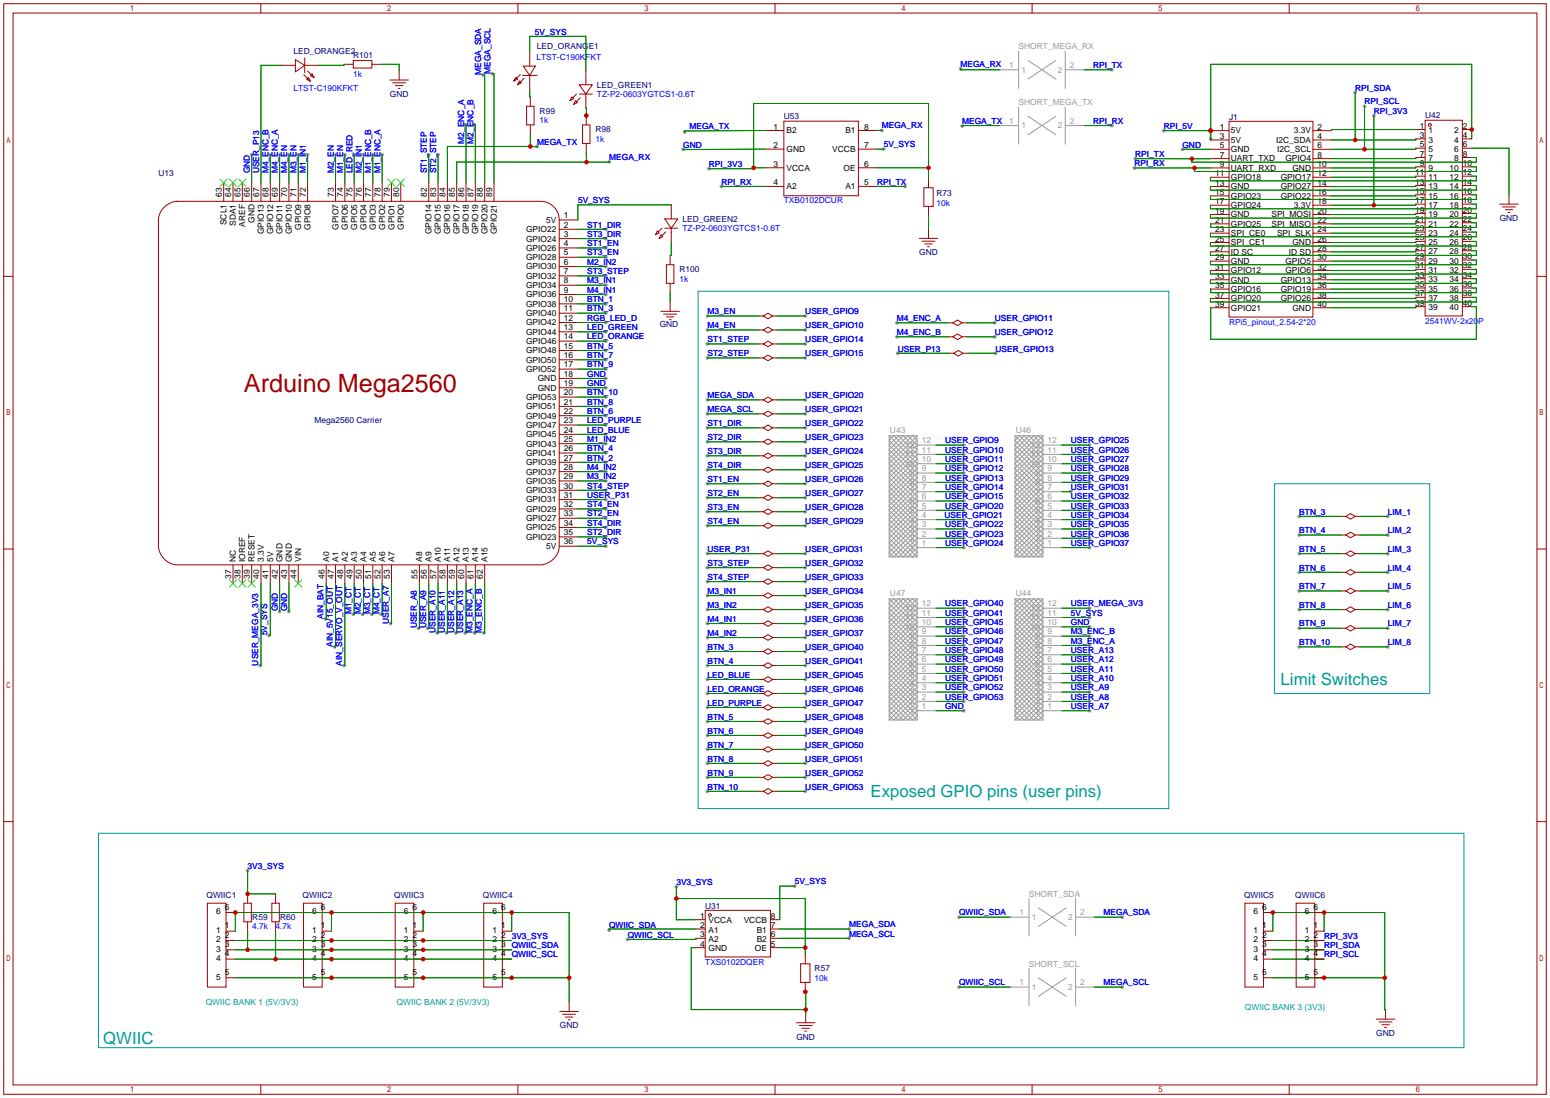
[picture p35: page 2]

Exposed GPIO pins (user pins)

# Dual H-Bridge

# Dual H-Bridge

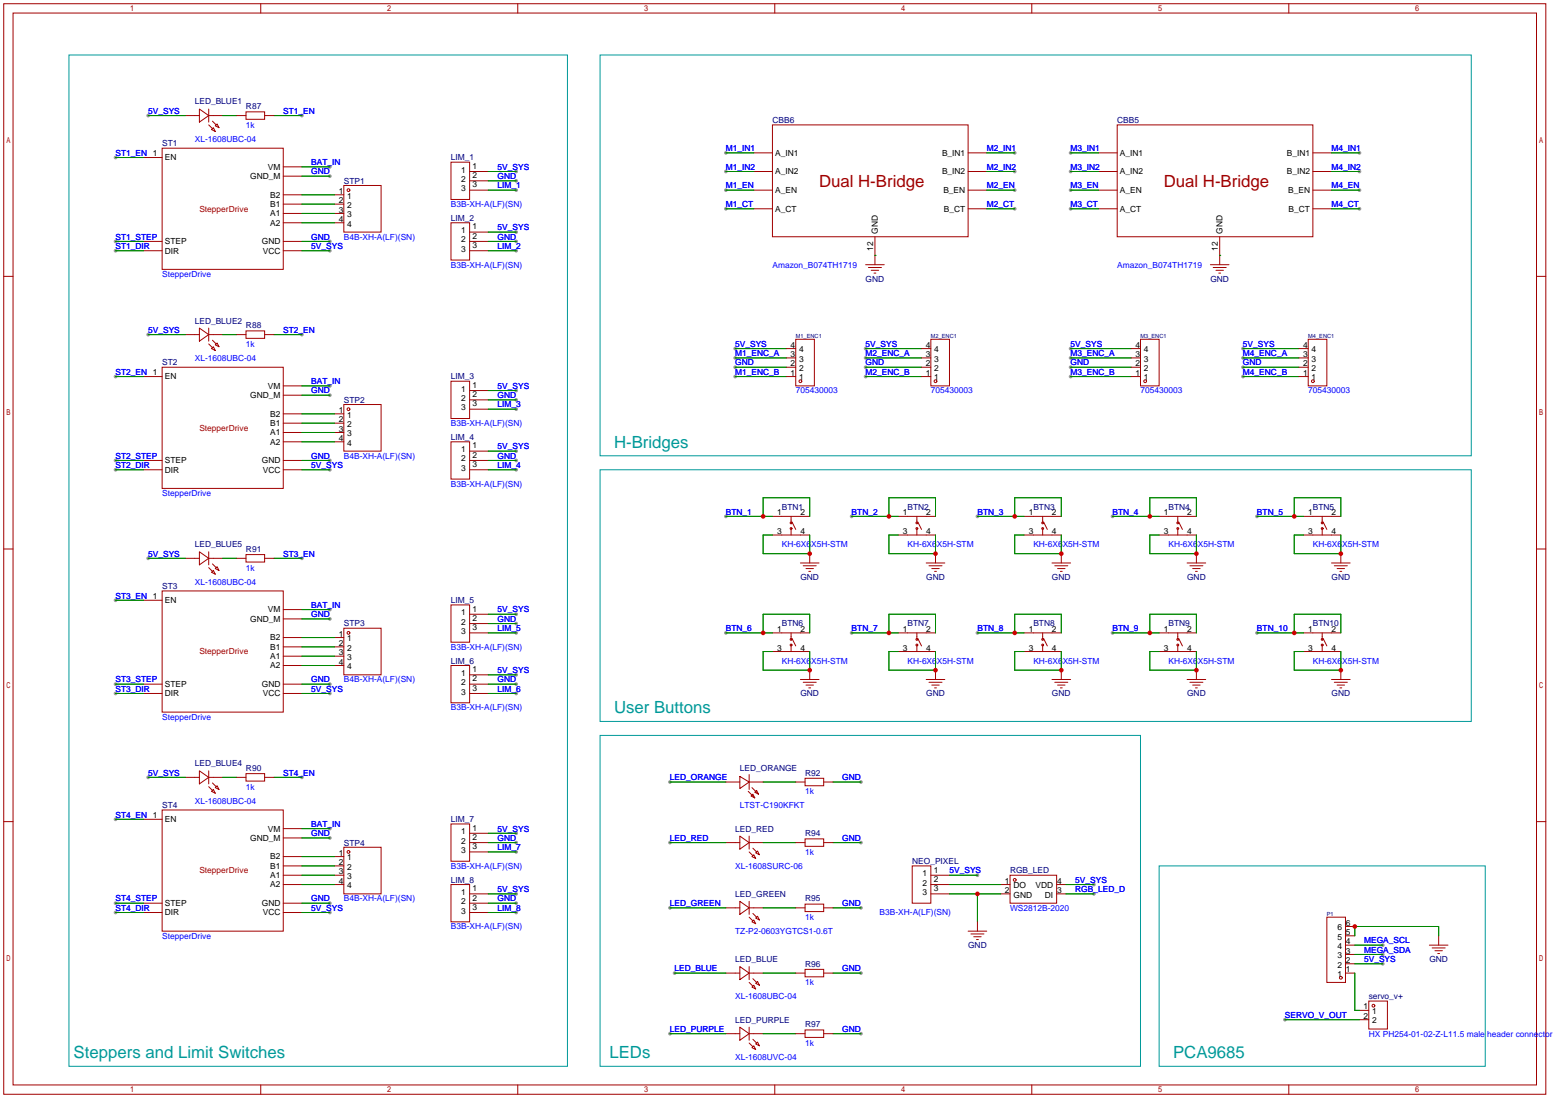
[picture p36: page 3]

Steppers and Limit Switches

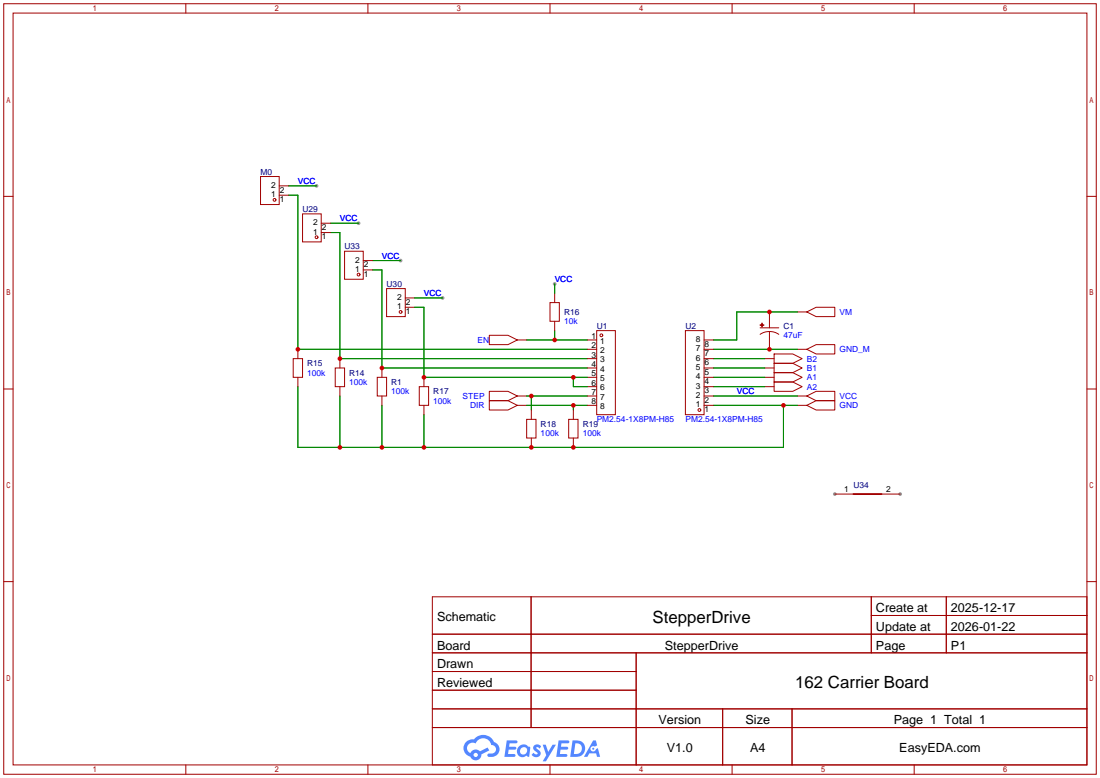
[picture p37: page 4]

Schematic | StepperDrive | Create at | 2025-12-17

Update at | 2026-01-22

Board | StepperDrive | Page | P1
Drawn | | 162 Carrier Board
Reviewed

Version | Size | Page 1 Total 1
V1.0 | A4 | EasyEDA.com

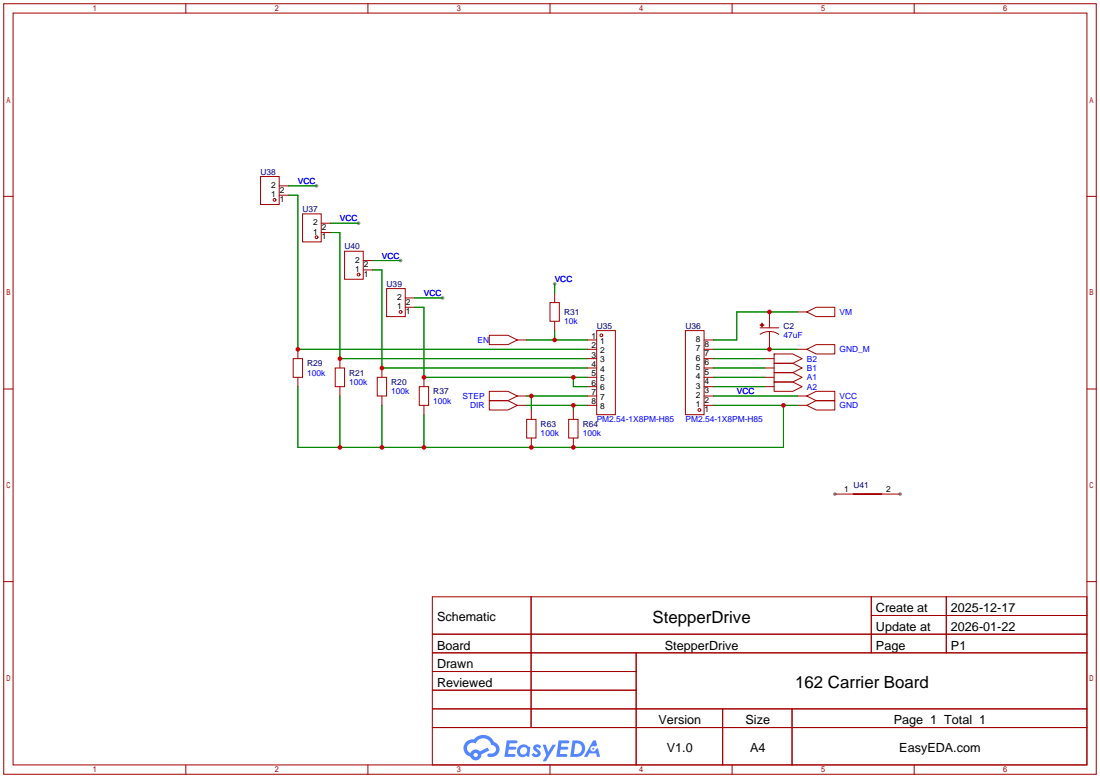
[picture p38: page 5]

Schematic | StepperDrive | Create at | 2025-12-17

Update at | 2026-01-22

Board | StepperDrive | Page | P1
Drawn | | 162 Carrier Board
Reviewed

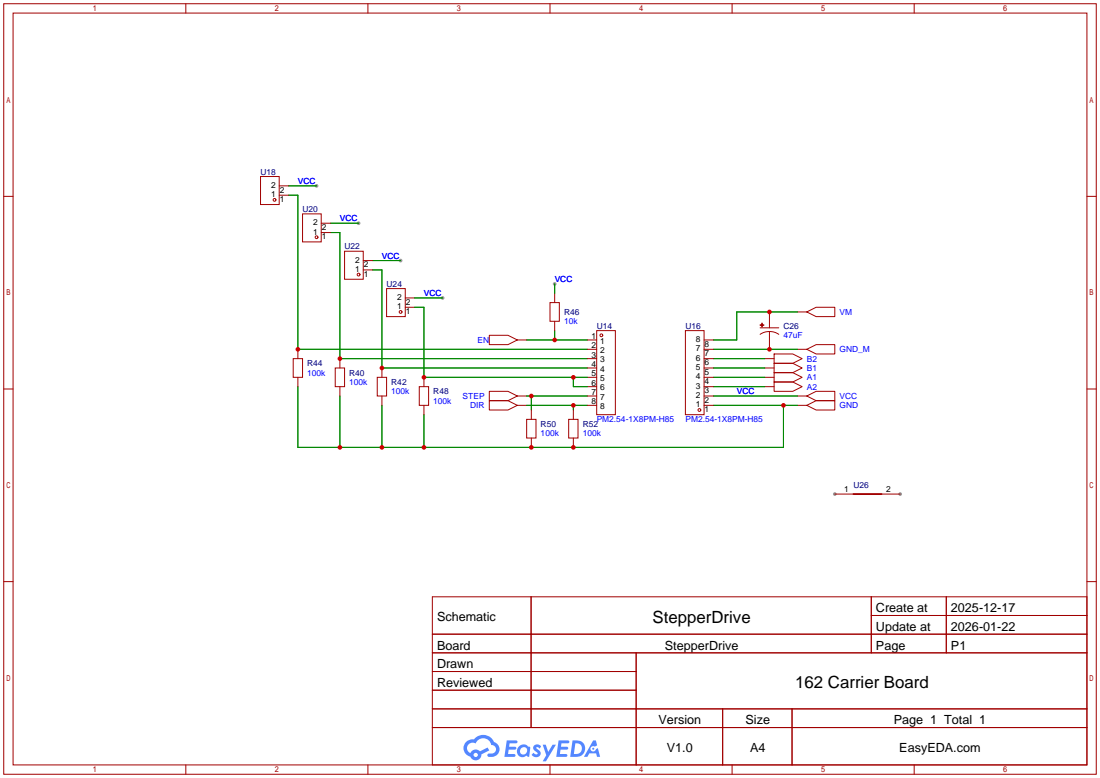
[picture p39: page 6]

Schematic | StepperDrive | Create at | 2025-12-17

Update at | 2026-01-22

Board | StepperDrive | Page | P1
Drawn | | 162 Carrier Board
Reviewed

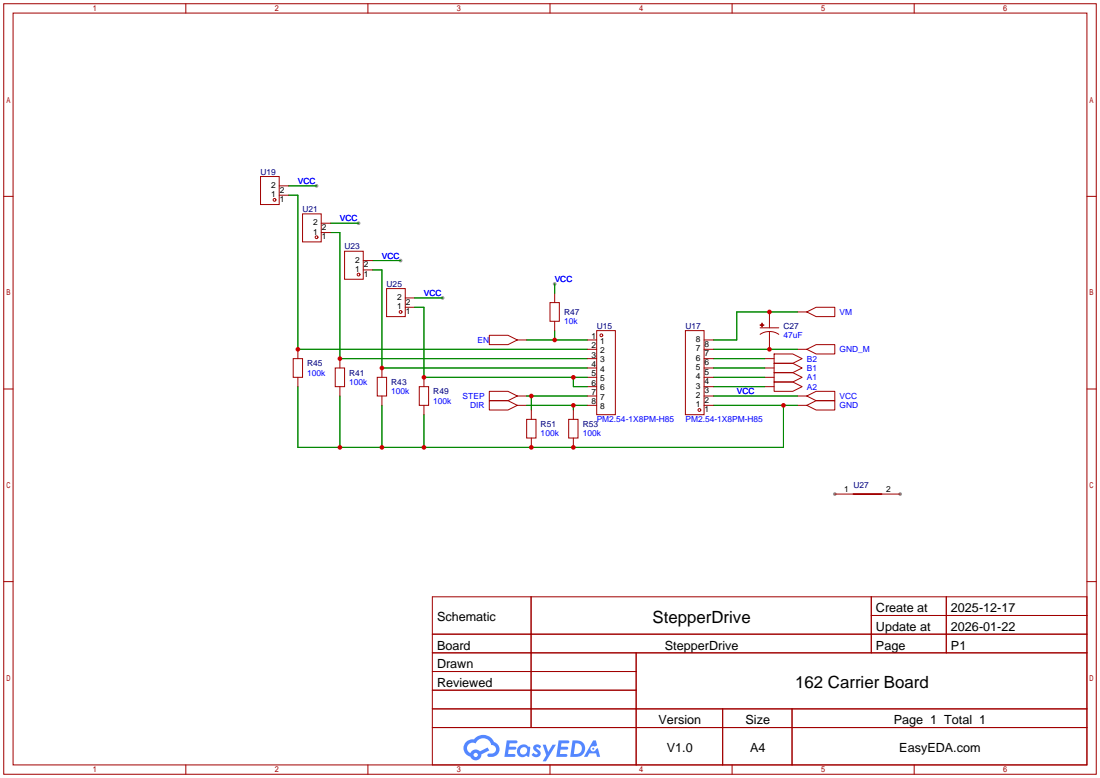
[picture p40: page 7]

Schematic | StepperDrive | Create at | 2025-12-17

Update at | 2026-01-22

Board | StepperDrive | Page | P1
Drawn | | 162 Carrier Board
Reviewed

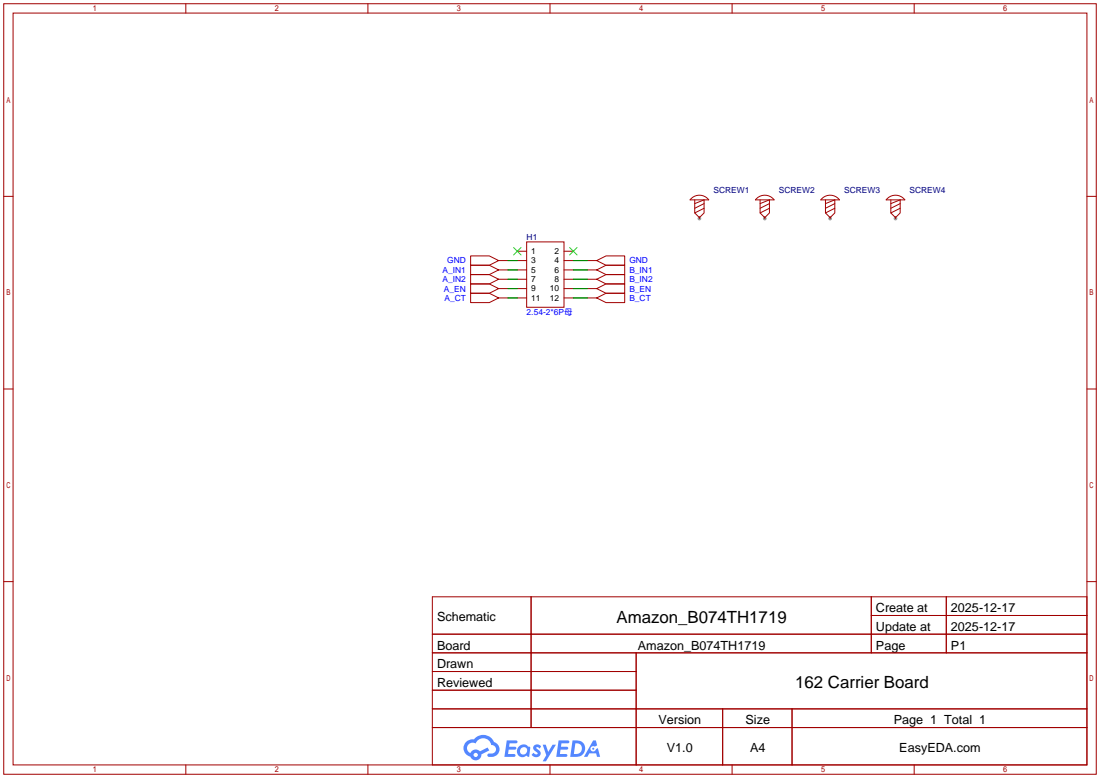
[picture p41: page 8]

Schematic | Amazon_B074TH1719 | Create at | 2025-12-17

Update at | 2025-12-17

Board | Amazon_B074TH1719 | Page | P1
Drawn | | 162 Carrier Board
Reviewed

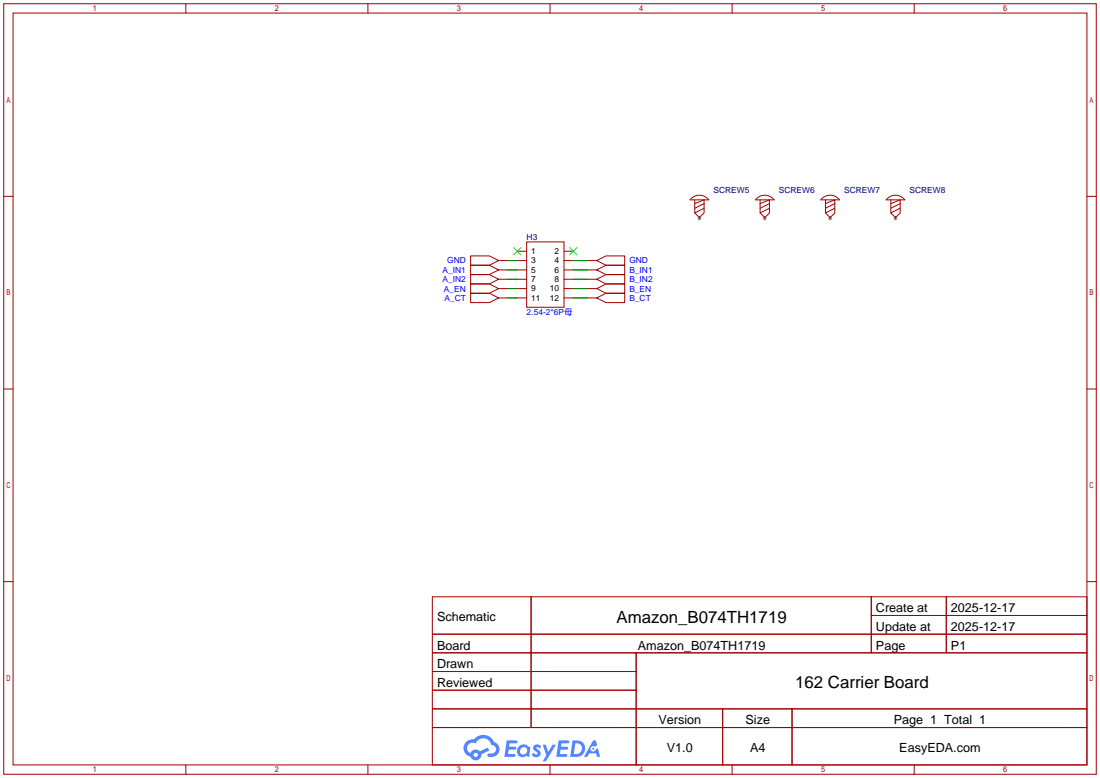
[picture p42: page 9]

Schematic | Amazon_B074TH1719 | Create at | 2025-12-17

Update at | 2025-12-17

Board | Amazon_B074TH1719 | Page | P1
Drawn | | 162 Carrier Board
Reviewed

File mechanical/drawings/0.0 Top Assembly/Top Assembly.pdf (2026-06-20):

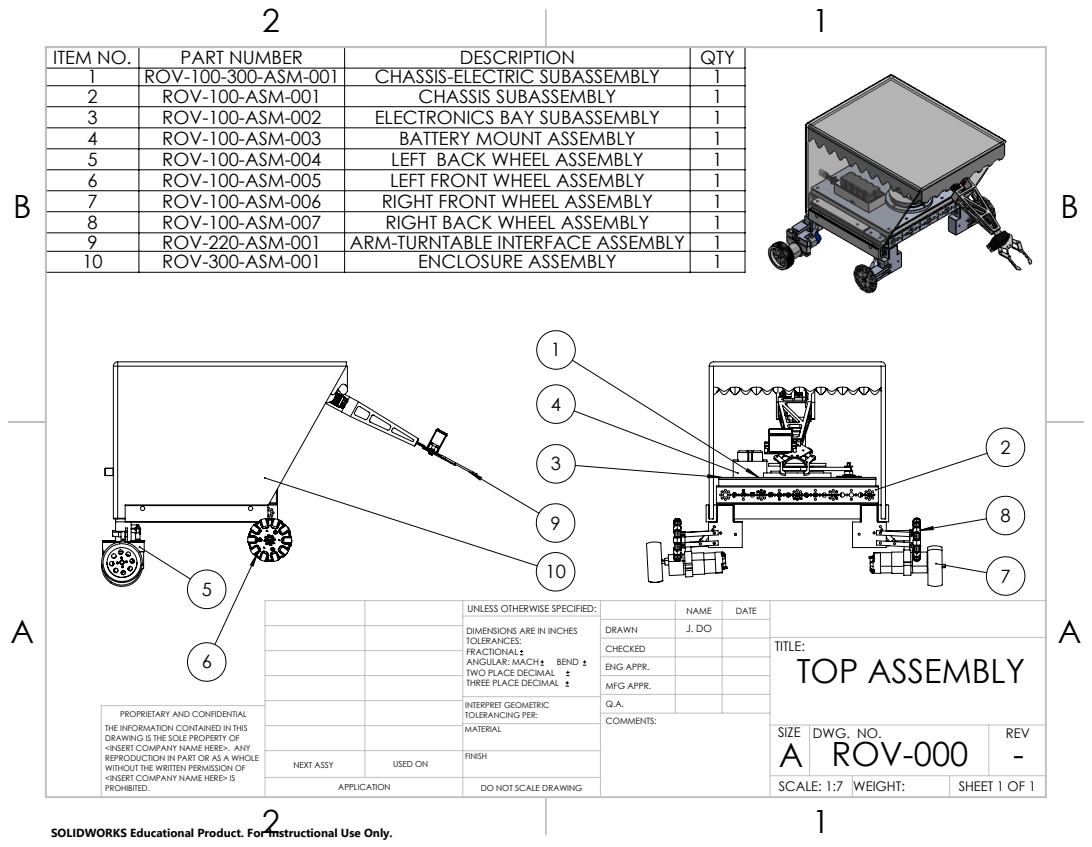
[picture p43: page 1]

ITEM NO. | PART NUMBER | DESCRIPTION | QTY
1 | ROV-100-300-ASM-001 | CHASSIS-ELECTRIC SUBASSEMBLY | 1
2 | ROV-100-ASM-001 | CHASSIS SUBASSEMBLY | 1
3 | ROV-100-ASM-002 | ELECTRONICS BAY SUBASSEMBLY | 1
4 | ROV-100-ASM-003 | BATTERY MOUNT ASSEMBLY | 1
5 | ROV-100-ASM-004 | LEFT BACK WHEEL ASSEMBLY | 1
6 | ROV-100-ASM-005 | LEFT FRONT WHEEL ASSEMBLY | 1
7 | ROV-100-ASM-006 | RIGHT FRONT WHEEL ASSEMBLY | 1
8 | ROV-100-ASM-007 | RIGHT BACK WHEEL ASSEMBLY | 1
9 | ROV-220-ASM-001 | ARM-TURNTABLE INTERFACE ASSEMBLY | 1
10 | ROV-300-ASM-001 | ENCLOSURE ASSEMBLY | 1

UNLESS OTHERWISE SPECIFIED: | | NAME | DATE
DIMENSIONS ARE IN INCHES TOLERANCES: FRACTIONAL ANGULAR: MACH BEND TWO PLACE DECIMAL THREE PLACE DECIMAL | DRAWN | J. DO

CHECKED | | | TITLE: TOP ASSEMBLY

ENG APPR.
MFG APPR.

INTERPRET GEOMETRIC TOLERANCING PER: | Q.A.

PROPRIETARY AND CONFIDENTIAL
THE INFORMATION CONTAINED IN THIS
DRAWING IS THE SOLE PROPERTY OF
<INSERT COMPANY NAME HERE>. ANY
REPRODUCTION IN PART OR AS A WHOLE
WITHOUT THE WRITTEN PERMISSION OF
<INSERT COMPANY NAME HERE> IS
PROHIBITED.

MATERIAL | | SIZE A | DWG. NO. ROV-000 | REV - DO NOT SCALE DRAWING

NEXT ASSY | USED ON | FINISH
APPLICATION | | | SCALE: 1:7 | WEIGHT: | SHEET 1 OF 1

SOLIDWORKS Educational Product. For Instructional Use Only.

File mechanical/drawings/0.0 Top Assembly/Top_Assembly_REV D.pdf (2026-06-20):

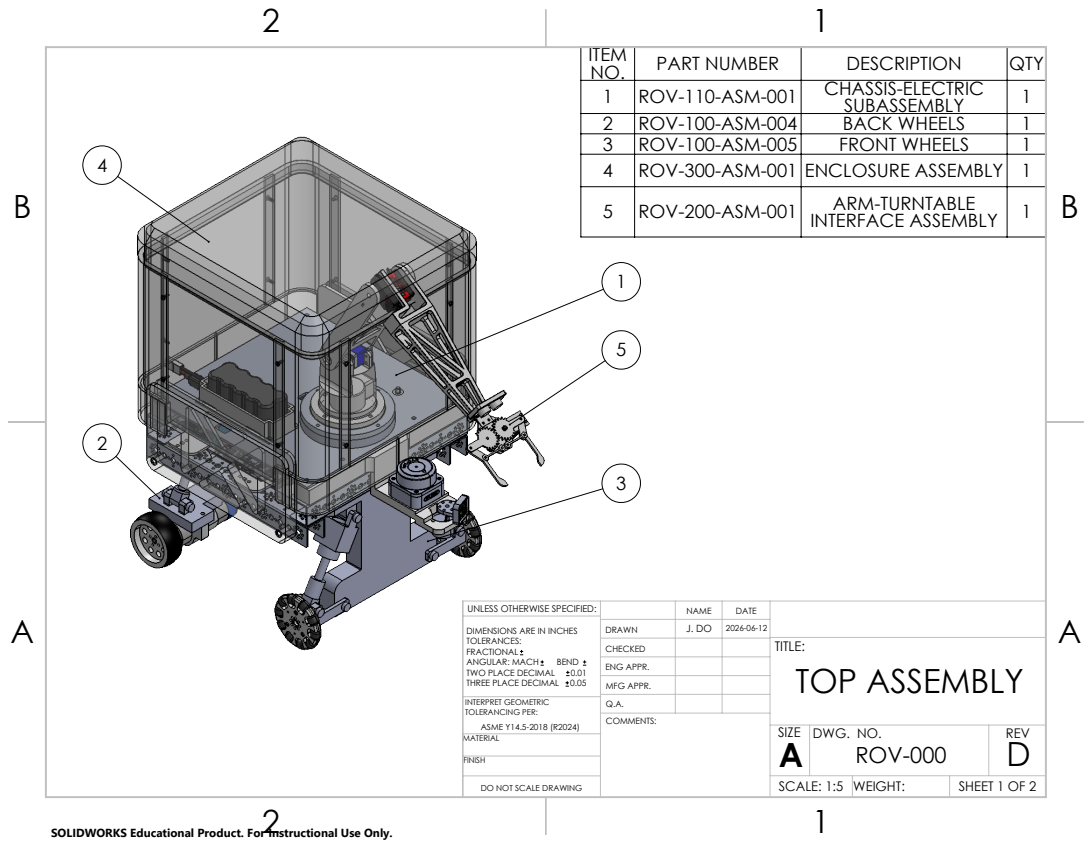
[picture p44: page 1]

ITEM NO. | PART NUMBER | DESCRIPTION | QTY
1 | ROV-110-ASM-001 | CHASSIS-ELECTRIC SUBASSEMBLY | 1
2 | ROV-100-ASM-004 | BACK WHEELS | 1
3 | ROV-100-ASM-005 | FRONT WHEELS | 1
4 | ROV-300-ASM-001 ENCLOSURE ASSEMBLY | | 1
5 | ROV-200-ASM-001 | ARM-TURNTABLE INTERFACE ASSEMBLY | 1

UNLESS OTHERWISE SPECIFIED: | | NAME | DATE
DIMENSIONS ARE IN INCHES TOLERANCES: FRACTIONAL ANGULAR: MACH BEND TWO PLACE DECIMAL 0.01 THREE PLACE DECIMAL 0.05 | DRAWN | J. DO | 2026-06-12

CHECKED | | | TITLE: TOP ASSEMBLY

ENG APPR.
MFG APPR.

INTERPRET GEOMETRIC TOLERANCING PER: ASME Y14.5-2018 (R2024) | Q.A.

SIZE A | DWG. NO. ROV-000 | REV D

DO NOT SCALE DRAWING | | SCALE: 1:5 | WEIGHT: | SHEET 1 OF 2

SOLIDWORKS Educational Product. For Instructional Use Only.

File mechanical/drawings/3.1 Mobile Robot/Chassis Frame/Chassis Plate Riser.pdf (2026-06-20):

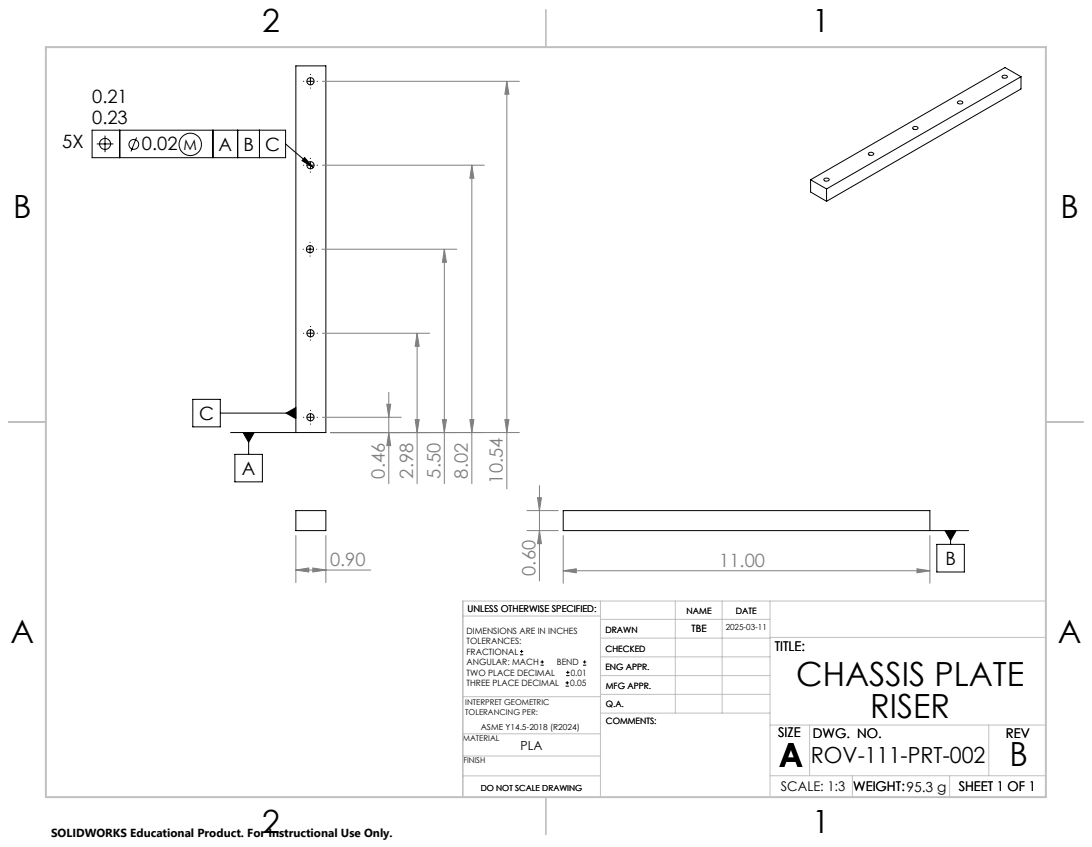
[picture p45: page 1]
SHEET 1 OF 1; SCALE: 1:3; WEIGHT:; DWG. NO.; REV; DO NOT SCALE DRAWING

UNLESS OTHERWISE SPECIFIED: | | NAME | DATE
DIMENSIONS ARE IN INCHES TOLERANCES: FRACTIONAL ANGULAR: MACH BEND TWO PLACE DECIMAL 0.01 THREE PLACE DECIMAL 0.05 | DRAWN | TBE | 2025-03-11 TBE

CHECKED | | | TITLE: TITLE: CHASSIS PLATE RISER

ENG APPR.
MFG APPR.

INTERPRET GEOMETRIC TOLERANCING PER: ASME Y14.5-2018 (R2024) | Q.A.

DO NOT SCALE DRAWING

SOLIDWORKS Educational Product. For Instructional Use Only.

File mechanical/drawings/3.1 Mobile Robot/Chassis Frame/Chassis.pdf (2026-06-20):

8X 0.22 THRU; SCALE 1 : 1

ITEM NO. | PART NUMBER | DESCRIPTION | QTY.
1 | 39068_txm-288mmchannel | CHASSIS RAILS | 4

2 | ROV-111-PRT-001 | MAIN CHASSIS PLATE | 1

3 | STD-M5-20 | M5 x 20 SHCS | 8
4 | STD-M5-NUT | M5 NUT | 12
5 | ROV-111-PRT-002 | CHASSIS PLATE RISER | 2

GENERAL NOTES:
1. ALL RAILS (ITEM 2) SHALL BE
ATTACHED TO MAIN PLATE
(ITEM 1), THROUGH iTEM 3
USING THE HARDWARE OF
ITEMS 4, 5, AND 6 AS SHOWN IN
DETAIL A.

UNLESS OTHERWISE SPECIFIED: | | NAME | DATE
DIMENSIONS ARE IN INCHES TOLERANCES: FRACTIONAL ANGULAR: MACH BEND TWO PLACE DECIMAL THREE PLACE DECIMAL | DRAWN | | 03-14-2026 TBE

CHECKED | | | TITLE: CHASSIS SUBASSEMBLY

ENG APPR.
MFG APPR.

INTERPRET GEOMETRIC TOLERANCING PER: | Q.A.
MATERIAL N/A | | SIZE B | DWG. NO. ROV-111-ASM-001 | REV A

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

NEXT ASSY | USED ON | N/A FINISH

APPLICATION | DO NOT SCALE DRAWING | | SCALE: 1:2 | WEIGHT: 1280 g | SHEET 1 OF 1

SOLIDWORKS Educational Product. For Instructional Use Only.

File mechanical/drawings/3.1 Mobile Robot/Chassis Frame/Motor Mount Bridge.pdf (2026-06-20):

PLA - 40% INFILL

ALL 4 CORNER HOLES ARE REFLECTIONS
ACROSS THE 2 CENTERLINES.

UNLESS OTHERWISE SPECIFIED: | | NAME | DATE
DIMENSIONS ARE IN INCHES TOLERANCES: FRACTIONAL ANGULAR: MACH BEND TWO PLACE DECIMAL .01 THREE PLACE DECIMAL .005 | DRAWN | J. DO

CHECKED | | | TITLE: MOTOR MOUNT BRIDGE

ENG APPR.
MFG APPR.

INTERPRET GEOMETRIC TOLERANCING PER: ASME Y14.5-2018 (R2024) | Q.A.

SIZE A | DWG. NO. ROV-114-PRT-001 | REV A

DO NOT SCALE DRAWING | | SCALE: 1:2 | WEIGHT: 63.5 g | SHEET 1 OF 1

SOLIDWORKS Educational Product. For Instructional Use Only.

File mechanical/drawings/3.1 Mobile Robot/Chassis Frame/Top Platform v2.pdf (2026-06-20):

4X 0.138 (M3 NORMAL CLEARANCE); 0.227 THRU; 0.223 THRU; 3.45 THRU; 6061 T6 ALUMINUM ALLOY

GENERAL NOTES:
1. OUTSIDE BOLT PATTERN CONSISTING OF (9)
M5 HOLES, AND THE CIRCULAR BEARING PATTERN
CONSISTING OF (4) M5 HOLES SHOULD BE DRILLED
USING AN M5 NORMAL CLEARANCE DRILL BIT.

UNLESS OTHERWISE SPECIFIED: | | NAME | DATE
DIMENSIONS ARE IN INCHES TOLERANCES: FRACTIONAL ANGULAR: MACH BEND TWO PLACE DECIMAL 0.01 THREE PLACE DECIMAL 0.05 | DRAWN | | 2025-03-11 TBE

CHECKED | | | TITLE: TOP PLATFORM

ENG APPR.
MFG APPR.

INTERPRET GEOMETRIC TOLERANCING PER: ASME Y14.5-2018 (R2024) | Q.A.

SIZE A | DWG. NO. ROV-111-PRT-001 | REV B

DO NOT SCALE DRAWING | | SCALE: 1:3 | WEIGHT: 612 g | SHEET 1 OF 1

SOLIDWORKS Educational Product. For Instructional Use Only.

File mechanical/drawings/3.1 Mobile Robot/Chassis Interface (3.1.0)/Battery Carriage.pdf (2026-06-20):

.13 X4 THRU

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

CHECKED | | | TITLE: BATTERY CARRIAGE

ENG APPR.
MFG APPR.

INTERPRET GEOMETRIC TOLERANCING PER: | Q.A.

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

ROV-330-ASM | | MATERIAL | | SIZE A | DWG. NO. ROV-PLT-330 | REV - DO NOT SCALE DRAWING

NEXT ASSY | USED ON | FINISH
APPLICATION | | | SCALE: 1:2 | WEIGHT: | SHEET 1 OF 1

SOLIDWORKS Educational Product. For Instructional Use Only.

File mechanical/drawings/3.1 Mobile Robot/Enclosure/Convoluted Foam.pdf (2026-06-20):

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

CHECKED | | | TITLE: Convoluted Foam

ENG APPR.
MFG APPR.

INTERPRET GEOMETRIC TOLERANCING PER: | Q.A.

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

ROV-300-ASM-001 | MATERIAL | | SIZE A | DWG. NO. ROV-300-PRT-002 | REV - DO NOT SCALE DRAWING

NEXT ASSY | USED ON | FINISH
APPLICATION | | | SCALE: 1:5 | WEIGHT: | SHEET 1 OF 1

SOLIDWORKS Educational Product. For Instructional Use Only.

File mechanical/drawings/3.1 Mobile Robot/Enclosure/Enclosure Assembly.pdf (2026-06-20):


ITEM NO. | PART NUMBER | DESCRIPTION | QTY.
1 | ROV-300-PRT-001 | Enclosure | 1
2 | ROV-300-PRT-002 | Convoluted Foam | 1
3 | ROV-300-PRT-003 | Sliding Rails | 2

UNLESS OTHERWISE SPECIFIED: | | NAME | DATE
DIMENSIONS ARE IN INCHES TOLERANCES: FRACTIONAL ANGULAR: MACH BEND TWO PLACE DECIMAL THREE PLACE DECIMAL | DRAWN | J. DO | 02/12/26

CHECKED | | | TITLE: Enclosure Assembly

ENG APPR.
MFG APPR.

INTERPRET GEOMETRIC TOLERANCING PER: | Q.A.
MATERIAL ABS | | SIZE A | DWG. NO. ROV-300-ASM-001 | REV - DO NOT SCALE DRAWING

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

NEXT ASSY | USED ON | FINISH
APPLICATION | | | SCALE: 1:10 WEIGHT: | | SHEET 1 OF 1

SOLIDWORKS Educational Product. For Instructional Use Only.

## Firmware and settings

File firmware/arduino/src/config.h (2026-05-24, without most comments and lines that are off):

#define CONFIG_H
#define FIRMWARE_VERSION        0x00090900  // Version 0.9.9
#define TLV_PROTOCOL_VERSION_MAJOR 4
#define TLV_PROTOCOL_VERSION_MINOR 0
#define BOARD_REVISION          0       // 0 = unspecified / unknown
#define RPI_BAUD_RATE           200000  // Stable bring-up rate for Mega2560 <-> RPi
#define HEARTBEAT_TIMEOUT_MS    500     // Disable actuators if heartbeat stops
#define I2C_INIT_CLOCK_HZ       100000
#define I2C_BUS_CLOCK_HZ        400000
#define SERVO_I2C_CLOCK_HZ      100000
#define I2C_WIRE_TIMEOUT_US     5000
#define UART_COMMS_FREQ_HZ      100     // UART service task
#define MOTOR_UPDATE_FREQ_HZ    200     // DC control compute round
#define SENSOR_UPDATE_FREQ_HZ   100     // Sensor dispatch task
#define IMU_UPDATE_FREQ_HZ      25      // IMU read + Fusion update cadence
#define USER_IO_FREQ_HZ         20      // LEDs / buttons / UI indications
#define STATUS_REPORTER_ENABLED 0       // 1 = emit [SYSTEM]/[TIMING]/[UART], 0 = disable
#define STATUS_REPORT_HZ        1       // Report frequency when enabled
#define FAULT_EVENT_LOG_ENABLED 1
#define FAULT_EVENT_MIN_INTERVAL_MS 100
#define DEBUG_BAUD_RATE         115200
#define DEBUG_LOG_BUFFER_SIZE   768
#define DEBUG_FLUSH_MAX_BYTES_PER_PASS 16
#define NUM_DC_MOTORS           4       // Total DC motor channels
#define DC_MOTOR_1_DIR_INVERTED 1       // 0=normal, 1=inverted
#define DC_MOTOR_2_DIR_INVERTED 1       // 0=normal, 1=inverted
#define DC_MOTOR_3_DIR_INVERTED 1       // 0=normal, 1=inverted
#define DC_MOTOR_4_DIR_INVERTED 1       // 0=normal, 1=inverted
#define NUM_STEPPERS            4       // Total stepper channels
#define NUM_SERVO_CHANNELS      16      // PCA9685 provides 16 channels
#define SERVO_CONTROLLER_ENABLED 1      // Enable PCA9685 servo driver
#define ENCODER_PPR             1440    // Pulses per revolution (manufacturer spec, for encoder_4x)
#define ENCODER_MAX_RPM         100     // Maximum expected motor RPM
#define ENCODER_2X              2       // 2x counting (phase A only)
#define ENCODER_4X              4       // 4x counting (both phases)
#define ENCODER_1_MODE          ENCODER_4X
#define ENCODER_2_MODE          ENCODER_4X
#define ENCODER_3_MODE          ENCODER_4X
#define ENCODER_4_MODE          ENCODER_4X
#define ENCODER_1_DIR_INVERTED  0       // 0=normal, 1=inverted
#define ENCODER_2_DIR_INVERTED  0       // 0=normal, 1=inverted
#define ENCODER_3_DIR_INVERTED  0       // 0=normal, 1=inverted
#define ENCODER_4_DIR_INVERTED  0       // 0=normal, 1=inverted
#define WHEEL_DIAMETER_MM   74.0f
#define WHEEL_BASE_MM       333.0f
#define INITIAL_THETA       90.0f
#define ODOM_LEFT_MOTOR     0 // MOTOR_1
#define ODOM_LEFT_MOTOR_DIR_INVERTED 0
#define ODOM_RIGHT_MOTOR    1 // MOTOR_2
#define ODOM_RIGHT_MOTOR_DIR_INVERTED 1
#define DC_PID_FREQ_HZ          800     // DC motor Timer1 round-robin slot (1.25 ms; 200 Hz per motor)
#define STEPPER_TIMER_FREQ_HZ   10000   // 10kHz interrupt rate (100µs period)
#define STEPPER_MAX_RATE_SPS    5000    // Maximum steps per second per motor
#define ENCODER_STALL_DETECTION     0    // 1=enabled, 0=disabled
#define ENCODER_FAIL_PWM_THRESHOLD  51   // ~20% of 255; below this = intentional slow/stop
#define ENCODER_FAIL_TIMEOUT_MS     500  // ms without encoder movement before fault declared
#define DC_CURRENT_SENSE_ENABLED    0    // 1=sample CT analog pins in DCMotor::service()
#define MOTOR_TASK_CATCHUP_BUDGET_US 1000 // max wall-clock catch-up budget per taskMotors() pass
#define UART_TASK_BUDGET_US      10000   // 10 ms = full 100 Hz tick period
#define PID_ISR_UART_BUDGET_US      80
#define STEPPER_ISR_UART_BUDGET_US  60
#define PID_ROUND_BUDGET_US    (1000000UL / MOTOR_UPDATE_FREQ_HZ)
#define RPI_SERIAL              Serial2 // Hardware serial port
class HardwareSerial;
class Print;
extern HardwareSerial &DEBUG_SERIAL_PORT;
extern Print &DEBUG_SERIAL;
#define TELEMETRY_SYS_STATE_RUN_MS        100
#define TELEMETRY_SYS_STATE_IDLE_MS       1000
#define TELEMETRY_SYS_POWER_RUN_MS        100
#define TELEMETRY_SYS_POWER_IDLE_MS       1000
#define TELEMETRY_DC_STATE_MS             20
#define TELEMETRY_STEP_STATE_MS           20
#define TELEMETRY_SERVO_STATE_MS          100
#define TELEMETRY_IMU_MS                  40
#define TELEMETRY_IMU_IDLE_MS             100
#define TELEMETRY_KINEMATICS_MS           40
#define TELEMETRY_KINEMATICS_IDLE_MS      100
#define TELEMETRY_IO_INPUT_STATE_MS       20
#define TELEMETRY_IO_OUTPUT_STATE_MS      100
#define DEVICE_ID               0x01    // Arduino device ID for TLV protocol
#define ENABLE_CRC_CHECK        1       // Enable CRC checks on TLV packets. Set to 0 to disable.
#define VELOCITY_LOWPASS_CONST  0.50f   // Low-pass weight on raw speed; y=(y+raw*k)/(1+k)
#define VELOCITY_ZERO_TIMEOUT   50      // Zero velocity timeout (milliseconds)
#define DEFAULT_POS_KP          5.0f
#define DEFAULT_POS_KI          0.0f
#define DEFAULT_POS_KD          0.5f
#define DEFAULT_VEL_KP          0.2f
#define DEFAULT_VEL_KI          4.0f
#define DEFAULT_VEL_KD          0.0f
#define PID_OUTPUT_MIN          -255    // Minimum PWM value
#define PID_OUTPUT_MAX          255     // Maximum PWM value
#define IMU_ENABLED             0
#define IMU_AD0_VAL             1       // SparkFun breakout default: AD0 high = 0x69
#define IMU_ACCEL_RANGE_G       2       // 2, 4, 8, or 16 g
#define IMU_GYRO_RANGE_DPS      250     // 250, 500, 1000, or 2000 dps
#define FUSION_GAIN             0.2f
#define FUSION_GYRO_RECOVERY_DPS 0.0f
#define FUSION_ACCEL_REJECTION  10.0f   // degrees of gravity disagreement
#define FUSION_MAG_REJECTION    20.0f   // degrees of magnetic disagreement
#define FUSION_RECOVERY_PERIOD  5       // seconds
#define ULTRASONIC_COUNT        0
#define MAG_CAL_MIN_SAMPLES     50
#define VBAT_ENABLED            1       // Battery voltage monitoring
#define V5_ENABLED              1       // 5V rail monitoring
#define VSERVO_ENABLED          1       // Servo rail monitoring
#define BATTERY_NIMH_8CELL    1   //  8-cell NiMH,  9.6 V nominal
#define BATTERY_NIMH_10CELL   2   // 10-cell NiMH, 12.0 V nominal  ← DEFAULT
#define BATTERY_LIPO_2S       3   //  2S LiPo,  7.4 V nominal
#define BATTERY_LIPO_3S       4   //  3S LiPo, 11.1 V nominal
#define BATTERY_LIPO_4S       5   //  4S LiPo, 14.8 V nominal
#define BATTERY_LIPO_5S       6   //  5S LiPo, 18.5 V nominal
#define BATTERY_LIPO_6S       7   //  6S LiPo, 22.2 V nominal (⚠ near 24 V hw limit)
#define BATTERY_CUSTOM        99  // Set VBAT_WARN_V/CUTOFF_V/OVERVOLTAGE_V manually
#define BATTERY_TYPE    BATTERY_NIMH_10CELL   // ← change this line to switch battery
#if   BATTERY_TYPE == BATTERY_NIMH_8CELL
  #define VBAT_WARN_V           8.4f   // 8 × 1.05 V
  #define VBAT_CUTOFF_V         8.0f   // 8 × 1.00 V — disable motors (prevents over-discharge)
  #define VBAT_OVERVOLTAGE_V   12.5f   // above max charge (~8 × 1.45 V)
#elif BATTERY_TYPE == BATTERY_NIMH_10CELL
  #define VBAT_WARN_V          10.5f   // 10 × 1.05 V
  #define VBAT_CUTOFF_V        10.0f   // 10 × 1.00 V
  #define VBAT_OVERVOLTAGE_V   15.5f   // above max charge (~10 × 1.45 V)
#elif BATTERY_TYPE == BATTERY_LIPO_2S
  #define VBAT_WARN_V           7.0f   // 2 × 3.5 V
  #define VBAT_CUTOFF_V         6.6f   // 2 × 3.3 V — LiPo damage threshold
  #define VBAT_OVERVOLTAGE_V    8.6f   // above 2 × 4.3 V
#elif BATTERY_TYPE == BATTERY_LIPO_3S
  #define VBAT_WARN_V          10.5f   // 3 × 3.5 V
  #define VBAT_CUTOFF_V         9.9f   // 3 × 3.3 V
  #define VBAT_OVERVOLTAGE_V   12.9f   // above 3 × 4.3 V
#elif BATTERY_TYPE == BATTERY_LIPO_4S
  #define VBAT_WARN_V          14.0f   // 4 × 3.5 V
  #define VBAT_CUTOFF_V        13.2f   // 4 × 3.3 V
  #define VBAT_OVERVOLTAGE_V   17.2f   // above 4 × 4.3 V
#elif BATTERY_TYPE == BATTERY_LIPO_5S
  #define VBAT_WARN_V          17.5f   // 5 × 3.5 V
  #define VBAT_CUTOFF_V        16.5f   // 5 × 3.3 V
  #define VBAT_OVERVOLTAGE_V   21.5f   // above 5 × 4.3 V
#elif BATTERY_TYPE == BATTERY_LIPO_6S
  #define VBAT_WARN_V          21.0f   // 6 × 3.5 V
  #define VBAT_CUTOFF_V        19.8f   // 6 × 3.3 V
  #define VBAT_OVERVOLTAGE_V   24.0f   // hw limit; 6S full charge = 25.2 V (not measurable)
#elif BATTERY_TYPE == BATTERY_CUSTOM
  #define VBAT_WARN_V          10.5f
  #define VBAT_CUTOFF_V        10.0f
  #define VBAT_OVERVOLTAGE_V   16.0f
#else
  #error "Unknown BATTERY_TYPE — see BATTERY_TYPE options in config.h"
#endif
#define VBAT_LOW_THRESHOLD  VBAT_WARN_V
#define VBAT_MIN_PRESENT_V      2.0f
#define VSERVO_MIN_PRESENT_V    4.0f
#define VBAT_DIVIDER_R1         50000.0f  // Upper resistor (Ω)
#define VBAT_DIVIDER_R2         10000.0f  // Lower resistor (Ω)
#define VBAT_DIVIDER_RATIO      ((VBAT_DIVIDER_R1 + VBAT_DIVIDER_R2) / VBAT_DIVIDER_R2)
#define V5_DIVIDER_RATIO        2.0f
#define VSERVO_DIVIDER_RATIO    3.0f
#define ADC_VREF                5.0f    // 5V reference
#define ADC_RESOLUTION          1024    // 10-bit ADC
#define NEOPIXEL_COUNT          1       // Number of WS2812B LEDs
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

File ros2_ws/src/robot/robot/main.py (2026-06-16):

# Uncomment exactly one import below to select the active program.

# ── Demos ─────────────────────────────────────────────────────────────────────
#from robot.programs.demos.full_competition_venue_run import run  # noqa: F401
from robot.programs.demos.precision_stack_manipulator_demo import run  # noqa: F401

# ── Navigation ────────────────────────────────────────────────────────────────
#from robot.programs.navigation.straight_line_test import run  # noqa: F401
#from robot.programs.navigation.lane_switch_obstacle_test import run  # noqa: F401
#from robot.programs.navigation.uturn_test import run  # noqa: F401
#from robot.programs.navigation.seg4_standalone_test import run  # noqa: F401
#from robot.programs.navigation.drive_both_wheels_test import run  # noqa: F401

# ── Manipulation (calibration + per-component tests) ──────────────────────────
#from robot.programs.manipulation.arm_ik_calibration_test import run  # noqa: F401
#from robot.programs.manipulation.arm_extend_retract_test import run  # noqa: F401
#from robot.programs.manipulation.elbow_calibration_test import run  # noqa: F401
#from robot.programs.manipulation.servo_calibration import run  # noqa: F401
#from robot.programs.manipulation.servo_range_test import run  # noqa: F401
#from robot.programs.manipulation.elbow_range_test import run  # noqa: F401
#from robot.programs.manipulation.shoulder_range_test import run  # noqa: F401
#from robot.programs.manipulation.gripper_open_close_test import run  # noqa: F401
#from robot.programs.manipulation.campan_range_test import run  # noqa: F401
#from robot.programs.manipulation.turntable_range_test import run  # noqa: F401
#from robot.programs.manipulation.turntable_home_test import run  # noqa: F401
#from robot.programs.manipulation.stepper_basic_move_test import run  # noqa: F401
#from robot.programs.manipulation.disable_servos import run  # noqa: F401
#from robot.programs.manipulation.heating_wire_test import run  # noqa: F401

# ── Perception (vision + lidar) ───────────────────────────────────────────────
#from robot.programs.perception.lidar_snapshot_test import run  # noqa: F401
#from robot.programs.perception.green_light_detect_test import run  # noqa: F401
#from robot.programs.perception.mallow_detection_range_test import run  # noqa: F401
#from robot.programs.perception.detection_vision_test import run  # noqa: F401

# ── Analysis (data recording + plotting) ──────────────────────────────────────
#from robot.programs.analysis.nav_data_recorder import run  # noqa: F401

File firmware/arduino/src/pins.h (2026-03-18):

/**
 * @file pins.h
 * @brief [Rev. B] Hardware pin definitions for Arduino Mega 2560
 *
 * This file contains all GPIO pin assignments matching the hardware design.
 * Pin definitions are separated from config.h for clarity and maintainability.
 *
 * NOTE: This file mirrors the GPIO table in README.md and pin_table_rev_B.md.
 *       Any hardware changes should be reflected here.
 *
 * Key changes from Rev. A (see pins_rev_A.h for archive):
 *   - M1 and M2 wheel motors now use both encoder channels on dedicated INT
 *     pins (INT0/INT1 for M1, INT5/INT4 for M2) for full 4x quadrature.
 *   - M3 and M4 encoders relocated to PCINT pins (A14/A15 and pins 11/12).
 *   - M1_EN moved 5→6 (Timer4 OC4A), M2_EN moved 6→7 (Timer4 OC4B).
 *   - LED_RED moved 11→5 (Timer3 OC3A).
 *   - M2_IN1 moved 12→4, M2_IN2 moved 13→30.
 *   - Pins 13 and 31 freed as general-purpose user GPIOs.
 *   - Analog expansion reduced to A7–A13 (A14/A15 used for M3 encoders).
 */

#ifndef PINS_H
#define PINS_H

// ============================================================================
// SERIAL COMMUNICATION
// ============================================================================

// Serial0 (USB) - pins 0/1 used by Arduino core
#define PIN_USB_RX              0       // USB Serial RX (programming/debug)
#define PIN_USB_TX              1       // USB Serial TX (programming/debug)

// Serial2 (Raspberry Pi UART) - pins 16/17
#define PIN_RPI_TX              16      // TX to RPi5 (via level shifter 5V→3.3V)
#define PIN_RPI_RX              17      // RX from RPi5 (via level shifter 3.3V→5V)

// NOTE: Serial1 (pins 18/19) NOT AVAILABLE — used by M2_ENC_A / M2_ENC_B
// NOTE: Serial3 (pins 14/15) NOT AVAILABLE — used by ST1_STEP / ST2_STEP

// ============================================================================
// I2C BUS
// ============================================================================

#define PIN_I2C_SDA             20      // I2C Data (Qwiic + PCA9685)
#define PIN_I2C_SCL             21      // I2C Clock (Qwiic + PCA9685)

// ============================================================================
// DC MOTOR 1 (Default Left/Right Wheel)
// ============================================================================

#define PIN_M1_EN               6       // PWM Enable (speed control) [Timer4 OC4A]
#define PIN_M1_IN1              8       // Direction control 1
#define PIN_M1_IN2              43      // Direction control 2
#define PIN_M1_ENC_A            2       // Encoder Phase A (INT0) — 4x quadrature
#define PIN_M1_ENC_B            3       // Encoder Phase B (INT1) — 4x quadrature
#define PIN_M1_CT               A3      // Current sense (analog)

// ============================================================================
// DC MOTOR 2 (Default Left/Right Wheel)
// ============================================================================

#define PIN_M2_EN               7       // PWM Enable (speed control) [Timer4 OC4B]
#define PIN_M2_IN1              4       // Direction control 1
#define PIN_M2_IN2              30      // Direction control 2
#define PIN_M2_ENC_A            18      // Encoder Phase A (INT5) — 4x quadrature
#define PIN_M2_ENC_B            19      // Encoder Phase B (INT4) — 4x quadrature
#define PIN_M2_CT               A4      // Current sense (analog)

// ============================================================================
// DC MOTOR 3 (Manipulator - Optional)
// ============================================================================

#define PIN_M3_EN               9       // PWM Enable (speed control)
#define PIN_M3_IN1              34      // Direction control 1
#define PIN_M3_IN2              35      // Direction control 2
#define PIN_M3_ENC_A            A14     // Encoder Phase A (PCINT14) — 4x via PCINT
#define PIN_M3_ENC_B            A15     // Encoder Phase B (PCINT15) — 4x via PCINT
#define PIN_M3_CT               A5      // Current sense (analog)

// ============================================================================
// DC MOTOR 4 (Manipulator - Optional)
// ============================================================================

#define PIN_M4_EN               10      // PWM Enable (speed control)
#define PIN_M4_IN1              36      // Direction control 1
#define PIN_M4_IN2              37      // Direction control 2
#define PIN_M4_ENC_A            11      // Encoder Phase A (PCINT5) — 4x via PCINT
#define PIN_M4_ENC_B            12      // Encoder Phase B (PCINT6) — 4x via PCINT
#define PIN_M4_CT               A6      // Current sense (analog)

// ============================================================================
// STEPPER MOTOR 1
// ============================================================================

#define PIN_ST1_STEP            14      // Step pulse
#define PIN_ST1_DIR             22      // Direction
#define PIN_ST1_EN              26      // Enable (active low)
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

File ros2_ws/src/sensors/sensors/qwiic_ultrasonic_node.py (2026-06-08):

"""
ROS2 driver for the SparkFun Qwiic Ultrasonic Distance Sensor (TCT40).

Reads distance via I2C (default address 0x2F) and publishes sensor_msgs/Range
on /ultrasonic_range at ~10 Hz.

Protocol: write any byte to trigger a measurement, wait ~80 ms, read 2 bytes
(big-endian) for distance in mm.

Parameters
----------
i2c_bus     : int   (default 1)    — /dev/i2c-<N>
i2c_address : int   (default 0x2F)
rate_hz     : float (default 10.0)
"""
from __future__ import annotations

import time

import rclpy
from rclpy.node import Node
from rclpy.qos import QoSProfile, ReliabilityPolicy, HistoryPolicy
from sensor_msgs.msg import Range

_BEST_EFFORT = QoSProfile(
    reliability=ReliabilityPolicy.BEST_EFFORT,
    history=HistoryPolicy.KEEP_LAST,
    depth=1,
)

MIN_RANGE_M = 0.02   # 2 cm
MAX_RANGE_M = 4.00   # 400 cm


class QwiicUltrasonicNode(Node):
    def __init__(self) -> None:
        super().__init__("qwiic_ultrasonic")

        self.declare_parameter("i2c_bus", 1)
        self.declare_parameter("i2c_address", 0x2F)
        self.declare_parameter("rate_hz", 10.0)

        self._bus_num = self.get_parameter("i2c_bus").value
        self._addr    = self.get_parameter("i2c_address").value
        self._rate_hz = float(self.get_parameter("rate_hz").value)

        self._pub = self.create_publisher(Range, "/ultrasonic_range", _BEST_EFFORT)
        self._bus = None
        self._last_err_log = 0.0
        self._consec_errors = 0
        self._open_bus()

        self.create_timer(1.0 / self._rate_hz, self._tick)
        self.get_logger().info(
            f"Qwiic ultrasonic node started "
            f"(I2C bus {self._bus_num}, addr 0x{self._addr:02X}, {self._rate_hz:.0f} Hz)"
        )

    def _close_bus(self) -> None:
        """Close the bus handle if open, swallowing any error during close."""
        if self._bus is not None:
            try:
                self._bus.close()
            except Exception:
                pass
            self._bus = None

    def _open_bus(self) -> None:
        # Always close any existing handle first — overwriting self._bus without
        # closing leaks the underlying file descriptor and quickly trips
        # [Errno 24] Too many open files.
        self._close_bus()
        try:
            import smbus2
            self._bus = smbus2.SMBus(self._bus_num)
            self.get_logger().info(f"Opened /dev/i2c-{self._bus_num}")
        except Exception as exc:
            self.get_logger().error(
                f"Cannot open I2C bus {self._bus_num}: {exc} — will retry each tick"
            )
            self._bus = None

    def _read_distance_mm(self) -> int | None:
        """Trigger a measurement and return distance in mm, or None on error."""
        if self._bus is None:
            self._open_bus()
            if self._bus is None:
                return None
        try:
            self._bus.write_byte(self._addr, 0x01)
            time.sleep(0.08)
            data = self._bus.read_i2c_block_data(self._addr, 0x01, 2)
            self._consec_errors = 0
            return (data[0] << 8) | data[1]
        except OSError as exc:
            self._consec_errors += 1
            now = time.monotonic()
            if now - self._last_err_log > 2.0:
                self.get_logger().warn(
                    f"I2C read error ({self._consec_errors} consec): {exc}"
                )
                self._last_err_log = now
            return None

    def _tick(self) -> None:
        dist_mm = self._read_distance_mm()

        msg = Range()
        msg.header.stamp = self.get_clock().now().to_msg()
        msg.header.frame_id = "ultrasonic_link"
        msg.radiation_type = Range.ULTRASOUND
        msg.field_of_view = 0.2618  # ~15 degrees
        msg.min_range = MIN_RANGE_M
        msg.max_range = MAX_RANGE_M

        if dist_mm is None or dist_mm == 0:
            # Sentinel: range > max_range signals invalid/no-echo
            msg.range = MAX_RANGE_M + 1.0
        else:
            msg.range = dist_mm / 1000.0

        self._pub.publish(msg)


def main(args=None) -> None:
    rclpy.init(args=args)
    node = QwiicUltrasonicNode()
    try:
        rclpy.spin(node)
    except KeyboardInterrupt:
        pass
    finally:
        node._close_bus()
        node.destroy_node()
        if rclpy.ok():
            rclpy.shutdown()


if __name__ == "__main__":
    main()

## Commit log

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2026-03-07 revert to 1M< baud
    [config.py]
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2026-04-04 Decouple serial ingest from ROS publishes in the bridge. Queue decoded messages on the bridge node thread so startup traffic does not stall fresh telemetry.
    [bridge_node.py]
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2026-04-10 Revert "Fix motor assignment overwritten by firmware SysOdomParamRsp"
    This reverts commit 7505d82375d44cb7f3508d1123de6abbe57d80ed.
    [robot.py]
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2026-04-16 fix(robot): improve startup pose wait and bridge/firmware feedback - may break Todd2 integration; verify before merging
    [main.py, robot.py]
2026-04-17 Resolved Conflicts in Robot.py and push changes made by Jimmy in Thursday lab.
    [robot.py]
2026-04-17 Restore correct TA robot.py
    [robot.py]
2026-04-24 Replaced Idle->Moving State Transition by Btn1 with auto start after 3 seconds. Also tuned orientation fusion to 0.0 and position fusion to 0.3
    [main.py, robot.py]
2026-04-29 changes fix gps and arduino serial issues
    [main.py]
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2026-04-30 fixed minor bug from prior merge with upstream due to difference in path variable name
    [main.py]
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2026-05-07 Updated hardware_map parameters and added TAG_ID = 17 as a parameter. Changed position_fusion to 0.1 in robot.py. Main acts as workplace to run tests, routines, or examples. New routines folder added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
    [hardware_map.py, robot.py]
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2026-05-07 Add final_demo, manipulator_demo, FSM convention fixes, TEST_PLAN update
    [_manipulator_config.py]
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2026-05-13 Changed and tested a few driving tests, moving PID configuration below start function in scripts. Set PID parameter in hardware map and fixed bug which incorrectly defined k_p. Issues still occur wit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
    [hardware_map.py, main.py]
2026-05-14 Add camera pan scan, ultrasonic ranging, and traffic light gating to demo
    - Replaced single-frame marshmallow detection with 3-frame camera pan sweep
    (Stepper 2) covering ±90° arc; picks highest-confidence hit across all frames
    - Added RANGING state: rotates turntable to marshmallow bearing, aims forearm
    horizontally for ultrasonic ranging, corrects height offset, runs IK from
    measured distance rather than assumed fixed distance
    - Updated turntable angle convention: [-90°, +180°] with 180° as stow;
    replaced TURNTABLE_SAFE_ARC_DEG with MIN/MAX/SCAN_ARC constants
    - final_demo.py: red LED + vision traffic light gate at start; stop sign
    removal detection before transitioning to ma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
    [_manipulator_config.py, campan_range_test.py]
2026-05-14 Move vision_traffic_light_drive to tests/scripts, rewrite TEST_PLAN
    - Moved vision_traffic_light_drive.py from programs/ to tests/scripts/
    with a full 3-terminal runbook at the top in copyable blocks
    - Restored correct Docker startup sequence (separate build/up/logs commands)
    and both source commands in the enter-container step
    - TEST_PLAN: added D0 (straight_line), D_vision (traffic light), M_campan
    (campan_range_test), M_ik (IK calibration); ordered all tests into phases;
    fixed M2 to not claim limit switch homing; updated hardware table with
    camera pan stepper row; removed stale limit switch row
2026-05-16 feat: add MJPEG camera stream and tracked tags panel to Nuevo UI
    - ground_localizer_node: start ThreadingHTTPServer at port 7778 serving
    annotated MJPEG preview (5 FPS by default, configurable via
    camera_stream_port / camera_stream_fps params). Frames are throttled
    in _on_rgb, JPEG-encoded at quality 50, and guarded by _stream_lock.
    CORS header allows direct browser connection from the lab LAN.
    - CameraWidget.tsx: toggleable UI widget with an <img> pointing at the
    Jetson MJPEG endpoint; shows "No signal" on connection error.
    - TagsPanel.tsx: lists all currently detected ArUco tags (tag_id, x, y
    in metres) from the tagDetections Zustand store slice that the
    existing bridge alr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
2026-05-16 feat: add admin-only recalibrate button to camera stream widget
    - ground_localizer_node: POST /recalibrate resets _calibrated and
    _using_cached_transform so the next frame with >=3 visible corners
    triggers a fresh SVD calibration. OPTIONS handler added for CORS
    preflight.
    - CameraWidget: recalibrate button rendered only for admin role (via
    authStore), sits below the live stream. Shows pending spinner,
    success, and error states with 3-second auto-reset.
    - GpsStatusCard: reverted to original (button moved to CameraWidget).
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2026-05-19 Add Qwiic ultrasonic, relay heating wire, stepper fixes, and manipulator config cleanup
    [_manipulator_config.py, arm_extend_retract_test.py, arm_ik_calibration_test.py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]
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2026-05-19 Changed MANUAL.md to be correct in equation for DRV8825 stepper driver v_ref voltage based off required amperage
2026-05-19 fix: switch default image_source back to color
    infra1 at 1280x720 is insufficient resolution for ArUco detection;
    color at 1920x1080 is needed.
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2026-05-21 Add marshmallow vision detection and fix IK coordinate offset
    - rule_based_detection: add HSV-based detect_marshmallow() (white/off-white
    blob with area, fill, and aspect filters)
    - vision_node: wire marshmallow detector into the per-frame pipeline
    - detection_vision_test: report bearing, elevation, pixel distance estimate,
    and IK target coordinates per candidate; fix robot_bearing sign convention
    - arm_kinematics: add camera_forward_offset_mm to ArmGeometry; fix
    detection_to_robot_frame to apply robot-front-to-turntable offset and
    correct CW→CCW bearing sign conversion
    - _manipulator_config: add ROBOT_FRONT_TO_TURNTABLE_MM, MARSHMALLOW_DIAMETER_MM,
    update ARM_SHOULDER_OFFSET_MM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
    [_manipulator_config.py, arm_kinematics.py]
2026-05-24 Add cup-first scanning, FK-corrected US ranging, and red cup detector
    Competition arm sequence overhaul across final_demo, manipulator_demo,
    and _manipulator_config:
    - SCANNING: cup-first detection — red cups are detected first, then a
    marshmallow is matched by bearing proximity (±10°) to confirm the
    stack. Unmatched cups (tennis balls / false case) are skipped.
    Falls back to direct marshmallow detection if no cup-mallow pairs
    found. Cup pinhole distance (95mm known diameter, bbox width) is
    used instead of marshmallow pinhole for better accuracy.
    - RANGING: arm stays in search pose — no intermediate arm movement.
    US reading is FK-corrected for the forearm's elevation angl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
    [_manipulator_config.py, config.h, main.py]
2026-05-27 Fix lane-switch obstacle avoidance, venue path, and uturn test
    - path_planner: fix pivot-spin bug in lane change — shifted path now
    only includes waypoints ahead of robot; smooth entry waypoint ensures
    ≤45° approach angle (lateral == forward); fix hardcoded current_lane
    from 'Left' to 'Center'
    - lane_switch_obstacle_test: fix path coords from venue-frame (1525,915)
    to local-frame (0,0); fix x_L from 610 to 0.0; auto-start after 3s
    instead of waiting for BTN_1
    - venue_no_obstacles_test: redesign with 5° arc steps, R=610 wide first
    arc (skips lane 2, avoids ramp at x=610), R=457.5 obs arcs; update
    Y_TOP_1/Y_TOP/Y_BOT constants
    - uturn_test: new standalone U-turn test using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
    [_manipulator_config.py, campan_range_test.py, hardware_map.py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]
2026-05-27 Small changes for obstacle avoidance
    [path_planner.py]
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2026-05-28 LiDAR Obstacle avoidance working and new implementations for turntable homing and safe turntable rotation functions in main demo scripts
    [_manipulator_config.py, main.py, path_planner.py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]
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2026-06-01 Add marshmallow-pick session handoff doc
    Captures the proven grab command, system/env notes, open issues, and
    camera-stream/debug one-liners so the work can be resumed without
    re-deriving the empirical arm poses.
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2026-06-02 Tune venue full-course test: per-segment configs and checkpoint restart support
    - Split nav tuning into per-segment CFG dicts (speed, lookahead, spacing,
    and avoidance params) so each leg is independently tunable.
    - Add _SEG_START so each segment defines its course-frame start position
    and heading; set_initial_theta + path offset let runs begin at any
    checkpoint with odometry resetting to (0, 0).
    - Bracket the obstacle zone with entry/exit offsets so the avoidance
    planner doesn't fight the 90° corners or treat walls as obstacles.
    - Drop SEG3B safe_dist 200→150 and avoidance_delay 420→250 so the
    hat-shape detour for cone 2 doesn't overshoot into the right lane
    and cone 3 can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
    [_manipulator_config.py, main.py]
2026-06-03 Add lidar pose reset at SEG3C, campan green-light pan, and driving state doc
    - venue_full_course_test.py: at the SEG3B→SEG3C transition, stop and run
    _lidar_wall_pose_reset() — fits a line to north-wall lidar points to
    correct heading drift and y-position, and uses the NE corner (2745,3965)
    to correct x; resets odometry and updates the coordinate origin so all
    downstream waypoints remain correct
    - venue_full_course_test.py: when AUTO_START=False, pan campan stepper to
    -30° before IDLE so the camera faces the traffic light
    - final_demo.py: heating wire switched from DC motor PWM to GPIO relay
    (enable_relay / set_relay / disable_relay)
    - driving_state.md: new session-handoff d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
2026-06-03 Add live vision feed widget to NUEVO UI and fix TEST_PLAN startup order
    - webapp.py: add GET /vision/latest.jpg (serves annotated frame from disk)
    and GET /vision/status (returns file age) — vision node must be running
    with debug_save_enabled=true (vision_debug.launch.py)
    - VisionFeedWidget.tsx: new component that polls /vision/latest.jpg every
    250 ms while expanded; shows a live/stale badge via /vision/status; falls
    back gracefully when the vision node is not running
    - App.tsx: add VisionFeedWidget above CameraWidget in the RPi Sensors column
    - TEST_PLAN.md: expand the vision node section with launch commands, camera
    recovery steps, and a full 4-terminal startup order table; the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
    [webapp.py]
2026-06-03 Prevent vision feed widget from blanking on transient image 404s
    Keep the <img> mounted after the first successful load so brief fetch
    failures no longer flip the widget to the "No vision signal" fallback,
    and slow the refresh from 250ms to 500ms.
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2026-06-03 Anchor marshmallow detection to red cups and refine ranging via cup bbox
    - vision: drop marshmallow detections not sitting on top of a red cup
    - turntable test: drop arm to point-down pose in RANGING, pan campan to the
    chosen target, refine distance from cup bbox + CUP_DIAMETER_MM (US becomes
    the fallback); save per-pan and decider scan snapshots when vision debug
    saving is enabled
    - marshmallow_pick: add --hold-s to keep re-commanding the gripper after a
    grab so it stays clamped past script exit
    - main.py: switch entry to turntable_pick_place_test
    - _manipulator_config: widen SHOULDER_SAFE range, tighten CUP_DIAMETER_MM to
    65 mm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
    [_manipulator_config.py, main.py]
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2026-06-04 Testes turntable pick more. Driving has error where it detects green light but doesnt proceed.
    [main.py]
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2026-06-05 Fix obstacle avoidance re-trigger, clearance formula, and add sim tuning tool
    path_planner.py:
    - Spatial re-trigger guard: block new avoidance until robot passes avoided cone y
    - Fix wrong-side clearance: compute shift to actual clearance point regardless
    of which side robot approaches the cone from
    - Guard remaining_path index access when only goal remains
    - Cap return_y at goal y to prevent overshoot
    venue_full_course_test.py:
    - SEG3B tuned params: safe_dist=181, offset=324, obs_range=450, delay=245,
    alpha_Ld=0.70, view_angle=70deg, speed=75
    - _load_path reads all avoidance params from cfg instead of hardcoding
    sim_obstacle_avoidance.py (new):
    - Interactive 2D simulator for tuning Pu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
    [path_planner.py]
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2026-06-06 Add arm kinematics simulator, switch IK to elbow-up, and tune RANGING
    arm_kinematics.py
    - inverse_kinematics() now takes elbow_up keyword (default True). Picks the
    IK branch where the elbow sits above the shoulder->gripper line (upper
    arm up, forearm down) — the only branch the NUEVO elbow can physically
    fold into. All existing callers automatically pick up the new default.
    _manipulator_config.py
    - New ARM_RANGING_SHOULDER_DEG=120 / ARM_RANGING_ELBOW_DEG=4 — tuned for the
    6"+cup-radius (=185 mm) mallow zone so US ranging hits every bearing
    across +/-90 with no hardware collisions
    - New PLACE_X/Y/Z_MM = (128, -226, -201) — validated drop position
    - Hardware envelope constan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
    [_manipulator_config.py, arm_kinematics.py, sim_arm_kinematics.py]
2026-06-06 Switch active target to venue_full_course_test, enable AUTO_START, fix LiDAR QoS
    [main.py]
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2026-06-06 SEG4 bump-zone slowdown, stop-sign range gating, traffic-light fix
    - Gate venue stop-sign trigger on bbox height (STOP_SIGN_MIN_FRAC) so the
    robot approaches closer before the 3s dwell instead of stopping on
    first sighting.
    - Split SEG4 into A (corner approach, 120 mm/s) and B (lane-5 south at
    70 mm/s) for the speed-bump zone, and move the finish to (2440, 280).
    - Fix traffic-light class-name mismatch: vision_node publishes
    "traffic light" (space) but venue_full_course_test and
    vision_traffic_light_drive queried "traffic_light"; strict-equality
    match in get_detections() returned nothing so the green-light start
    never fired.
    - Add rate-limited IDLE vision debug print so future c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
    [qwiic_ultrasonic_node.py]
2026-06-07 Fix I2C bus thrashing in qwiic ultrasonic node
    On every transaction error the node was nulling self._bus, which forced
    a fresh smbus2.SMBus open on the next tick. At 10 Hz that meant a
    continuous open/fail/open/fail storm whenever the sensor wasn't acking,
    disrupting other devices on /dev/i2c-1 (notably the PCA9685 servo
    driver — corrupted PWM writes were making the arm snap to extreme
    angles and the gripper open unprompted).
    Keep the bus fd open across transient OSErrors, throttle the warning
    log to once every 2 s with a consecutive-error count, and narrow the
    except from bare Exception to OSError.
    [qwiic_ultrasonic_node.py]
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2026-06-07 Manipulator + venue tuning, new elbow calibration test, stepper helpers
    _manipulator_config:
    - Gripper open/close updated to match new mechanical hard stops:
    OPEN 0→29, GRAB 45→50, CLOSE 120→90, ROAST 60→70.
    - TURNTABLE_HOME_OFFSET_DEG 171→169 to correct the post-home turntable
    overshoot to forward (was landing 2° CW of 0°).
    manual_ik_pick_place_test:
    - Switch turntable + campan helpers to fire-and-forget step_move with a
    calculated sleep based on max velocity. _wait_stepper_idle consistently
    misses the brief IDLE→active→IDLE transition on the steppers, so the
    blocking wait was stalling the FSM for the full timeout while the move
    itself completed correctly.
    - SAF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
    [_manipulator_config.py, elbow_calibration_test.py, main.py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]
2026-06-07 Manual IK pick/place close to working, slight residual offset
    Pick and place both execute end-to-end with the mallow held through
    transport. Remaining issue: the gripper consistently lands a few mm
    off the IK target in z (and the place target lands slightly back in
    x) for reasons not yet fully understood — likely a combination of
    arm sag under load, servo non-linearity at the wider pulse range,
    and small calibration mismatches.
    robot.py:
    - _SERVO_MIN_US / _SERVO_MAX_US widened to 500 / 2500 µs so script
    set_servo() commands have the same authority as UI sliders (was
    driving only the middle 50% of the DS3235 mechanical range).
    _manipulator_config.py:
    - Arm lengths re-measured: L1 155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
    [_manipulator_config.py, robot.py]
2026-06-07 Add Manual Test preset to arm kinematics sim
    Replaces the Mallow 6" preset with the position from
    manual_ik_pick_place_test.py (bearing 0, 193.8 mm from camera, -81.37 mm
    height) so the same target can be visualised in the sim and used to
    sanity-check IK angles before running on hardware.
    [sim_arm_kinematics.py]
2026-06-07 Add LiDAR-driven cup-pick demo path and detection-range test
    For the competition manipulation task, replaces the
    camera-bbox-pinhole-distance + forearm-ultrasonic approach with a
    LiDAR-first cup-stack mapper plus camera-only target classification.
    LiDAR scans every cup stack in one horizontal slice (±5 mm radial vs.
    ±20-30 mm for the camera bbox); camera identifies which stack has the
    purple-coloured marshmallow and snaps the height to one of three
    measured competition tiers (8/18/24 cups on 3 mm cardboard).
    Adds:
    * venue cup-tier height constants and snap_to_venue_tier_mm() helper in
    _manipulator_config.py, plus TURNTABLE_X_IN_BODY_MM for body→turntable
    frame conversion of lidar po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
    [_manipulator_config.py, sensors.py]
2026-06-08 Purple-mallow detector + 4-stack venue config
    Vision: rule-based detector now matches blue-violet HSV (H 120-160 S 60+
    V 50+) and labels detections "purple" — required because the competition
    mallows are dyed, not white. filter_marshmallows_on_red_cups passes
    mallows through when no red cup is in frame so the 9-cup stack (cup falls
    below the camera frame) still detects.
    Manipulator config: replaced the old 8/18/24 stack tier set with the new
    competition layout — four stacks of 9/11/14/16 cups at measured heights
    168/180/200/214 mm above cardboard. snap_to_venue_tier_mm() picks from
    the new tier list.
    Detection-range test: simplified to a single forward capture (no campan
    sweep), with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
    [_manipulator_config.py, main.py, path_planner.py]
2026-06-08 Restore full lane-switch shift with clearance gate for SEG3B avoidance
    - Restore working full-offset lane shift: dx = self.offset and
    current_lane = 'Right'/'Left' (lane tracking) on trigger. Avoidance
    re-commit only fires for cones on the opposite side from current lane,
    preserving zig-zag behaviour.
    - Keep the clearance gate (needed_offset > 10 with the OLD lateral-gap
    formula) so the planner only triggers when the robot doesn't already
    have safe_dist of clearance — avoids the failure where a full-offset
    shift toward the empty lane lands on top of the next cone.
    - Keep the spatial re-trigger guard, the len(remaining_path) >= 2
    waypoint guard, and the retur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
    [main.py, path_planner.py]
2026-06-08 Revert path_planner.py + sim_obstacle_avoidance.py to working state
    Restores both files to their state at commit 4155180 (the last known-good
    obstacle-avoidance configuration from Fri Jun 5). Verified on hardware:
    robot now avoids cones cleanly with the SEG3B venue config that was
    already in venue_full_course_test.py.
    What was broken in HEAD and why
    -------------------------------
    Two upstream commits regressed the planner between 4155180 and HEAD:
    a772d38 ("Purple-mallow detector + 4-stack venue config") changed two
    things in path_planner.py:
    * Re-enabled the dead `lidar_offset_mm = 100.0` shift that adds 100mm
    forward to every robot-frame obstacle. In the sim, this is a pure
    ph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
    [path_planner.py]
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2026-06-08 Driving status notes + SEG3B pause/heading-print fix
    driving_state.md: refresh segment status — SEG1, SEG2, and traffic-light
    detection are now almost always perfect; SEG3 obstacle avoidance generally
    clears the cones but accumulates a 30-50 degree heading error that breaks
    the SEG3C exit straight; SEG4 speed-bump pacing and the correct stop
    location for the stop sign are still undecided.
    venue_full_course_test.py: add a 3-second LED-blink pause after SEG3B so
    the operator gets an unmistakable visual cue and 3 s to nudge the rover
    before SEG3C runs. Fix the theta prints — get_odometry_pose already
    returns degrees, so math.degrees() was multiplying by 57.3 and turning
    "142 deg" into "814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
    [path_planner.py]
2026-06-09 SEG3B retune + goal-y obstacle filter + full-SEG3 sim scenario
    - path_planner: filter obstacles past goal_y so the north wall and any
    past-goal cones can't trigger a detour. Lets SEG3B safely extend up to
    the wall without the wall-as-obstacle U-turn bug.
    - venue_full_course_test: bump SEG3B lookahead 140->290, safe_dist
    190->230, alpha_Ld 0.70->0.90 for smoother detours; drop
    OBS_EXIT_OFFSET_MM 900->400 so SEG3B reaches y=3100 and dodges any
    real cone the course can place. Previous values left commented for
    quick revert.
    - sim_obstacle_avoidance: new "seg3_full" scenario runs all three SEG3
    sub-phases (3A approach / 3B obstacle / 3C exit) with their real
    configs in sequence.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
    [path_planner.py]
2026-06-10 Add seg4 standalone test, organize main.py, tighten cup-scan window
    - seg4_standalone_test: drops the venue checkpoint logic and runs SEG4
    (east leg → south leg, with optional stop-sign dwell) from (0,0)
    facing east on pure odometry. Lets SEG4 be exercised independently
    without GPS/AprilTag fusion or the segment-restart frame math.
    - main.py: regrouped imports under venue / manipulator / calibration /
    vision headers, deduped repeated commented imports, added the new
    seg4_standalone_test entry.
    - hardcoded_cup_pick_place_test: scan-time bearing tolerance narrowed
    from the shared 10° to a script-local 4° so adjacent stacks can't
    share a marshmallow detection across pans.
    Co-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
    [main.py]
2026-06-10 Perimeter wall margins + merge SEG4 path + SEG3B alpha_Ld back to 0.70
    - Inset all perimeter corners (TOP/EAST=200mm, BOTTOM=20mm) so pure-pursuit
    overshoot during the 90° right turns stops short of the walls.
    - Collapse SEG4_EAST_PATH + SEG4_SOUTH_PATH into one continuous SEG4_PATH and
    give SEG4 SEG2-style config (speed=130, lookahead=300). The split layout
    was stopping the robot at the corner facing east with a target due south,
    which collapsed forward_scale and produced the slow-turn jitter.
    - SEG3B alpha_Ld back to 0.70 for less detour overshoot.
    - main.py back on venue_full_course_test; AUTO_START on.
    Known issue: SEG3B still occasionally clips the west wall after passing the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
    [main.py]
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2026-06-11 Hardcoded 4-stack IK pick-place test + retract/release fixes
    manual_ik_pick_place_test.py is now a 4-stack hardcoded selector
    (PICK_STACK_INDEX 1=leftmost..4=rightmost) with the campan-axis
    measurement convention. Key fixes:
    - Turntable rotation uses atan2(pick_y, pick_x) from the turntable
    axis, not the camera-frame bearing — the previous off-axis pick
    missed by ~180 mm because the camera→turntable offset was baked
    into the bearing.
    - PICK_FORWARD_OFFSET_MM is a single 205 mm knob covering the dot
    position relative to the turntable axis.
    - Raised place z by PLACE_Z_LIFT_MM so the shoulder stays above 90°
    on side drops and the forearm clears the rover body.
    - _safe_arm_retrac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
    [main.py]
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2026-06-16 Reorganize robot package: consolidate programs/, split into subfolders
    Replaces the confusing robot/robot/tests/scripts/ (runtime hardware programs,
    not pytest tests) with a single robot/robot/programs/ tree organized into
    five descriptive subfolders. Renames the two final demos to portfolio-quality
    names and cleans extraneous comments from both.
    Package layout
    robot/robot/
    _manipulator_config.py shared arm/servo constants (now alongside
    hardware_map.py at package root)
    programs/
    demos/ final headline programs
    full_competition_venue_run.py (was venue_full_course_test.py)
    precision_stack_man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
    [_manipulator_config.py, arm_extend_retract_test.py, arm_ik_calibration_test.py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]
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
